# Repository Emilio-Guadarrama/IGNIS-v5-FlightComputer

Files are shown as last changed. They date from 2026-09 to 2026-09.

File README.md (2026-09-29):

# IGNIS v5 Flight Computer
### Ignitia Rocket Lab · Tecnológico de Monterrey GDL

---

## What is this?

IGNIS v5 is the fifth revision of Ignitia Rocket Lab's SRAD (Student Researched and Developed)
flight computer, a general-purpose avionics platform for high-power student rockets.

It handles the full flight from liftoff to recovery: sensor fusion, apogee detection,
pyrotechnic deployment, real-time LoRa telemetry, GNSS tracking and flight data logging.
Apogee is detected in flight rather than pre-programmed, so the same board can fly
missions from 500 m to 3 km without hardware changes.

---

## Competitions

IGNIS is used in the competitions Ignitia Rocket Lab takes part in or plans to join:

| Competition | Name | Location |
|---|---|---|
| **IREC** | Intercollegiate Rocket Engineering Competition, Spaceport America Cup | New Mexico, USA |
| **LASC** | Latin American Space Challenge | Brazil |
| **ENMICE** | Encuentro Mexicano de Ingeniería en Cohetería Experimental | Mexico |

---

## What's New in v5

v5 includes the lessons from the bench tests, flight tests and design reviews of the
previous versions. **All the areas of opportunity identified in earlier revisions have been solved**:

- **Reliability:** improved USB-C, power and pyro circuits.
- **Sensors:** updated IMU and barometer with a wider measurement range.
- **Manufacturability:** all assembled parts are available for **assembly at JLCPCB**, with alternates available in Mexico.
- **Documentation:** consistent schematic sheets and net names, and a BOM ready for assembly.

---

## Hardware at a Glance

| Block | Component |
|---|---|
| MCU | ESP32-S3-WROOM-1-N16R8 · 16 MB Flash / 8 MB PSRAM |
| RF Telemetry | RFM95W · 915 MHz LoRa · SMA antenna port |
| GNSS | u-blox SAM-M10Q · integrated patch antenna |
| IMU | LSM6DSV32X · 6-DOF · ±32 g / ±4000 dps |
| Barometer | Infineon DPS368 *(BMP280 drop-in compatible)* |
| Storage | MicroSD · SPI · card detect |
| Power | Dual AMS1117 · VBAT → 5 V → 3.3 V · battery voltage monitoring |
| USB | USB-C 2.0 · ESD protected · native USB programming |
| Debug | JST-SH 4-pin UART |
| Pyro | 2 channels, optically isolated MOSFET deployment with continuity sensing |
| Indicators | 3× WS2812B RGB · status LEDs · piezo buzzer |
| PCB | 4-layer · Altium Designer · JLCPCB fabrication and assembly |
| Apogee range | Adaptive, real-time apogee detection · 500 m to 3 km rockets |

---

## System Architecture

```mermaid
flowchart TD
    BAT[VBAT<br/>vehicle battery]

    BAT --> LDO5[AMS1117-5.0<br/>VBAT to 5 V]
    LDO5 --> RAIL5[5 V rail]
    USB[USB-C 2.0] --> ORING[Schottky power path]
    ORING --> RAIL5
    RAIL5 --> LDO33[AMS1117-3.3<br/>5 V to 3.3 V]
    LDO33 --> RAIL33[3.3 V rail]

    USB --> USBPROT[ESD protection]
    USBPROT --> MCU[ESP32-S3-WROOM-1-N16R8<br/>16 MB Flash / 8 MB PSRAM]
    BAT --> VMON[Battery voltage divider]
    VMON --> MCU

    RAIL33 --> IMU[LSM6DSV32X IMU<br/>±32 g / ±4000 dps]
    RAIL33 --> BARO[DPS368 barometer<br/>BMP280 footprint compatible]
    RAIL33 --> GNSS[u-blox SAM-M10Q GNSS]
    RAIL33 --> LORA[RFM95W LoRa<br/>915 MHz]
    RAIL33 --> SD[MicroSD<br/>SPI + card detect]

    IMU --> MCU
    BARO --> MCU
    GNSS --> MCU
    MCU <--> LORA
    MCU <--> SD
    LORA --> ANT[SMA antenna]

    MCU --> PYRO[2 × optically isolated<br/>pyro channels]
    BAT --> PYRO
    PYRO --> CONT[Continuity sensing]
    CONT --> MCU

    MCU --> IND[3 × WS2812B · status LEDs<br/>piezo buzzer]
    MCU <--> DEBUG[JST-SH 4-pin UART debug]
```

---

## Project Structure

```
IGNIS-v5-FlightComputer/
├── Schematics/
│   ├── Main.SchDoc
│   ├── Power.SchDoc
│   ├── RF_LoRa_&_GPS.SchDoc
│   ├── Sensors.SchDoc
│   ├── Storage.SchDoc
│   ├── Indicators.SchDoc
│   └── Pyros.SchDoc
├── PCB/
│   └── IGNIS_v5.PcbDoc
├── Libraries/
├── BOM/
└── Fabrication/
```

---

## Design & Development

**Lead Designer & Author:** [Emilio Guadarrama](https://github.com/Emilio-Guadarrama)  
Vice President, Ignitia Rocket Lab · Avionics & Electronics Lead

**Pyro Circuit:** Aristoteles Prieto  
**Team President:** Maximiliano Funoy Serrano  
**Faculty Advisor:** Dr. José Luis Henríquez Mercado

## Team

**Ignitia Rocket Lab**  
Tecnológico de Monterrey, Campus Guadalajara

📧 ignitia.rocketlab@gmail.com

---

## License

This project is open source under the [MIT License](LICENSE). You are free to use, modify and
share the design, including for your own rockets, as long as the original copyright notice is kept.

---

**Contact the author:** Emilio Guadarrama · [emilio.guadarrama@outlook.com](mailto:emilio.guadarrama@outlook.com)

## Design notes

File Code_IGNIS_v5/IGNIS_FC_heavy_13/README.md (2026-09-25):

# IGNIS v2 Flight Computer — firmware v13

Ignitia Rocket Lab · Tecnológico de Monterrey, Campus Guadalajara
LASC 2026 · Rocket Challenge, Mission ID 22

Post-FLIGHT051 / FLIGHT052 revision. FLIGHT052 is the flight where the FC
reset mid-descent and lost the entire post-apogee trace that the RRC3 backup
altimeter still has — this revision's centerpiece is a resume mechanism so
that doesn't happen again, plus the pyro-circuit correction the netlists
turned up. Every change is traced to a number in the flight logs or to the
schematic/netlists. Read `docs/CHANGELOG.md` first (v13 section is at the
top).

```
IGNIS_FC_heavy_13/
├── IGNIS_FC_heavy_13.ino    main sketch (boot counter, NO-GO tone + banner, RTC resume)
├── Config.h                 thresholds, interlocks, mode flags, pin map, RTC/I2C/flush tuning
├── FlightData.h             shared struct + lastPyroEventMs + RtcFlightState (v13 resume struct)
├── FlightState.h            FSM, baro velocity, tilt, failsafes, interlock, resume/sync (v13)
├── Pyro.h                   gate drive limiting, fire-event timestamp, RTC fired-flag persistence (v13)
├── DataLogger.h             post-pyro bounded flush, forensic CSV columns + `resumed` (v13), resume-reopen
├── Telemetry.h              98-byte v11/v12 packet — UNCHANGED this revision, see note below
├── Sensors.h                readBattery() extracted for the boot NO-GO, I2C timeout + runtime recovery (v13)
├── StatusIndicator.h        NOGO_MELODY, preflightNoGo(), persistent LED2
├── Dashboard.h              MODE / FSM / BOOT rows, NO-GO warnings (no longer cites a past flight — see CHANGELOG)
├── docs/
│   ├── CHANGELOG.md              <- read this first (v13, then v12, then v11)
│   ├── PREFLIGHT_VALIDATION.md   <- REC 8.4.2 test plan
│   ├── LIBRARIES.md              versions, UART jig, compile flags
│   └── install_libraries.sh
└── groundstation/
    ├── GroundStation_TelemetryPacket_v12.h   <- still named v12: packet layout is unchanged, see note below
    └── telemetry_parser_v12.py
```

**Groundstation files are still named `_v12` on purpose.** v13 only adds a
column to the SD CSV (`resumed`) — it does not touch `TelemetryPacket`, the
radio packet struct. Renaming files that carry no actual change would just
make history harder to follow; rename them the revision the packet itself
changes.

## Flight-configuration flags — CHECK THESE EVERY TIME

| Flag | Flight value | Effect if wrong |
|---|---|---|
| `GROUND_TEST_MODE` | **false** | If true: altitude interlock drops to 1.5 m — a bump can fire the drogue on the ground |
| `SINGLE_EVENT_MODE` | `true` unless BOTH channels read `cont:OK` | If false with an unwired channel: fires into an open loop, which is a reset risk |
| `APOGEE_TIMEOUT_MS` | Burnout→apogee time + margin | Too short: deployment at high speed, shredded parachute |
| `MIN_APOGEE_ALT_M` | 30 m | Too high: no deployment on an underperforming flight |
| `RTC_RESUME_ENABLED` (new, v13) | **true** | If false: an in-flight reset goes back to the FLIGHT051/052 behavior — reboots cold into `STATE_ARMED` and loses the rest of the flight |
| `I2C_TIMEOUT_MS` / `I2C_FAIL_RECOVERY_THRESHOLD` (new, v13) | 50 ms / 10 | Too low: spurious bus-recovery resets on a momentarily slow but otherwise fine bus |
| `PYRO_WINDOW_FLUSH_INTERVAL_MS` (new, v13) | 100 ms | Too low: back to near-every-row blocking SD flushes right after a fire, one of this revision's own watchdog-reset suspects |

The boot banner prints all of these (plus `last_op` and, on a resume boot, a
`RESUME:` banner line). Read it.

## Before you flash anything

1. **This has not been compiled.** Brace and parenthesis balance was verified
   programmatically on every file; that is not a clean build. Compile first
   and fix trivial errors rather than assuming a patch is wrong.
2. **Verify `Wire.setTimeOut()` against your installed ESP32 Arduino core
   version.** It's a real API on recent cores; confirm it before flashing
   rather than discovering a compile error on the pad.
3. **Bench-test the RTC resume path itself, in `GROUND_TEST_MODE`.** Force a
   reset mid-flight-simulation (e.g. power-cycle or trigger the watchdog
   deliberately) and confirm the FC comes back in the correct phase, with
   `resumed=1` in the next CSV rows and the same log file continuing rather
   than a new one. This is the core new mechanism in v13 and it has not been
   flight- or bench-verified yet.
4. **Determine why `pyro1_cont` reads 0.** Still open — this needs a
   physical continuity check on the CH1 e-match loop, it is not something
   firmware can diagnose or fix.
5. ~~Fit the 330 Ω gate resistors.~~ **Resolved — not actually missing.**
   The netlists (`Pyros.NET`/`Pyros2.NET`) confirm `R34` (100 Ω) is present
   in series with the fire-side opto LED, and ignition current is switched
   by an isolated MOSFET (`Q5`), not the opto. See `docs/CHANGELOG.md`
   v13 "Closed from v12."
6. **Re-tune `APOGEE_TIMEOUT_MS`** to the predicted profile. It is a
   deployment trigger, not a comment.
7. **Update the ground station in the same commit, if you change the radio
   packet.** Not needed for v13 itself (see the groundstation note above),
   but the packet is 98 bytes and the struct is packed — a mismatch decodes
   silently into garbage the moment it does change.

## The two sentences that matter

FLIGHT051→FLIGHT052: the flight computer reset mid-coast — confirmed
`reset_reason=5` (interrupt watchdog), battery steady at ~8.0 V throughout,
before any pyro command existed — then rebooted cold into `STATE_ARMED` and
detected the entire rest of the flight (apogee, descent, landing) as if it
were a new, stationary boot. The RRC3 backup altimeter has the full descent
trace; the FC's own SD log does not. v13's RTC resume mechanism exists
specifically so a reset like this keeps the flight computer *in* the flight
instead of restarting it.

FLIGHT018 (carried forward from v12, still true): the flight software
commanded a drogue fire at 0.80 m *below* the launch reference, off a hand
jerk on a 3-metre pulley. The v12 altitude interlock exists so that cannot
happen again, and v13 does not change it.

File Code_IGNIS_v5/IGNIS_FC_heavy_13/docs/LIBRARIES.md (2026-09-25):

# Libraries and toolchain — IGNIS FC v11

Third-party libraries are **not bundled** in this archive. They carry their own
licences, and vendoring frozen copies into the flight repo is how version
drift becomes untraceable — you already have one instance of that (the
installed RadioHead build has no `setSyncWord()`, which is why `Telemetry.h`
writes register `0x39` directly).

Install from Library Manager or with the script below, then record the exact
versions you flew in the mission report.

---

## Board package

| Item | Value |
|---|---|
| Core | `esp32:esp32` (Espressif Systems) |
| Version | **3.3.10** — this is what the codebase targets |
| Board | ESP32S3 Dev Module |
| Flash Size | 8 MB (64 Mb) — module is `ESP32-S3-WROOM-1-N8R8` |
| PSRAM | **OPI PSRAM** (8 MB Octal) |
| Partition Scheme | 8M with spiffs (3MB APP / 1.5MB SPIFFS) |
| USB CDC On Boot | Enabled (leave Disabled if programming over the UART jig) |
| Upload Speed | 921600 (drop to 115200 on the UART jig if unstable) |

The core version matters. `StatusIndicator.h` branches on
`ESP_ARDUINO_VERSION_MAJOR >= 3` for the LEDC API — the `< 3` branch is a
defensive fallback that has **not** been validated on this hardware.

## Libraries

| Library | Author | Version used | Notes |
|---|---|---|---|
| RadioHead | Mike McCauley | **1.122** (as installed) | `RH_RF95` only. `setSyncWord()` absent — do not "fix" `Telemetry.h` by calling it |
| TinyGPSPlus | Mikal Hart | 1.1.0 | NMEA parsing, `Sensors.h` |
| Adafruit NeoPixel | Adafruit | 1.12.3 | WS2812B status LEDs |

Built into the ESP32 core, nothing to install: `SPI`, `SD`, `Wire`,
`Preferences`, `esp_system`, `driver/gpio`.

BMP180 and MPU6050 use raw-register drivers in `Sensors.h`. Do **not** install
`Adafruit_BMP085` or `Adafruit_MPU6050` — they are not used and will only
confuse whoever picks this up next.

---

## Install

```bash
arduino-cli core update-index
arduino-cli core install esp32:esp32@3.3.10

arduino-cli lib install "RadioHead"
arduino-cli lib install "TinyGPSPlus@1.1.0"
arduino-cli lib install "Adafruit NeoPixel@1.12.3"
```

`install_libraries.sh` in this folder does the same and then prints the
resolved versions so you can paste them into the mission report.

## Compile

```bash
arduino-cli compile \
  --fqbn esp32:esp32:esp32s3:PSRAM=opi,FlashSize=8M,PartitionScheme=default_8MB,CDCOnBoot=cdc \
  --warnings all \
  IGNIS_FC_heavy_11
```

## Upload over the UART jig (bypasses the failing USB-C connectors)

Five of the flight computers have intermittent or dead USB-C. The connector is
only needed for programming — the boards log and fly correctly on battery
power alone. A CP2102 or CH340 adapter on the UART0 pins removes the
dependency entirely.

```
Adapter TX  ->  IO44  (ESP32 U0RXD)
Adapter RX  ->  IO43  (ESP32 U0TXD)
Adapter GND ->  board GND
Boot button ->  IO0 to GND
Reset       ->  EN to GND (momentary)
```

Entering download mode: hold IO0 low, pulse EN low then release, release IO0.

```bash
arduino-cli upload -p /dev/ttyUSB0 \
  --fqbn esp32:esp32:esp32s3:PSRAM=opi,FlashSize=8M,CDCOnBoot=default \
  IGNIS_FC_heavy_11
```

Set **USB CDC On Boot: Disabled** when programming this way, or `Serial` output
goes to the USB peripheral instead of UART0 and the console will look dead.

---

## Compile verification status

This firmware has **not** been compiled against the real toolchain — the build
environment used to produce these patches has no ESP32 core installed. Brace
and parenthesis balance was verified programmatically on every file; that is
not the same as a clean compile.

**Compile it before you flash anything, and fix trivial errors rather than
assuming a patch is wrong.**

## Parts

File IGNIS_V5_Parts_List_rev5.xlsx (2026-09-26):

IGNIS V5 component list
Mouser, DigiKey and SnapMagic links open a search for the exact part number. Stock checked Sep 25, 2026.
Status |  | Component name | ID # (part number) | Designator on schematic | # | LCSC | UNIT Electronics | Mouser MX | DigiKey MX | SnapMagic (symbol + footprint) | Notes
MICROCONTROLLER
Keep | TRUE | ESP32-S3 module 16 MB / 8 MB PSRAM | ESP32-S3-WROOM-1-N16R8 | MCU1 | 1 | C2913202 (https://www.lcsc.com/product-detail/C2913202.html) | UNIT (https://uelectronics.com/producto/esp32-s3-wroom-1-n16r8-16mb-flash/) | Mouser (https://www.mouser.mx/c/?q=ESP32-S3-WROOM-1-N16R8) | DigiKey (https://www.digikey.com.mx/es/products/result?keywords=ESP32-S3-WROOM-1-N16R8) | SnapMagic (https://www.snapeda.com/search/?q=ESP32-S3-WROOM-1-N16R8) | Fix USB D+/D− swap on Main sheet
POWER
Keep | TRUE | LDO 5 V | AMS1117-5.0 | U1 | 1 | C6187 (https://www.lcsc.com/product-detail/C6187.html) | UNIT (https://uelectronics.com/producto/ams1117-regulador-smd-5v-1a-sot-223/) | Mouser (https://www.mouser.mx/c/?q=AMS1117-5.0) | DigiKey (https://www.digikey.com.mx/es/products/result?keywords=AMS1117-5.0) | SnapMagic (https://www.snapeda.com/search/?q=AMS1117-5.0) | Kept for V5. Large copper + thermal vias; thermal test decides V6
Keep | TRUE | LDO 3.3 V | AMS1117-3.3 | U2 | 1 | C6186 (https://www.lcsc.com/product-detail/C6186.html) | UNIT (https://uelectronics.com/producto/ams1117-regulador-smd-3-3v-1a-sot-223/) | Mouser (https://www.mouser.mx/c/?q=AMS1117-3.3) | DigiKey (https://www.digikey.com.mx/es/products/result?keywords=AMS1117-3.3) | SnapMagic (https://www.snapeda.com/search/?q=AMS1117-3.3) | Kept (user decision)
Changed | TRUE | Schottky 40 V / 2 A SMA | SS24 | D1 | 1 | C50645 (https://www.lcsc.com/product-detail/C50645.html) | UNIT (https://uelectronics.com/producto/schottky-40v-2a-sma-ss24/) | Mouser (https://www.mouser.mx/c/?q=SS24) | DigiKey (https://www.digikey.com.mx/es/products/result?keywords=SS24) | SnapMagic (https://www.snapeda.com/search/?q=SS24) | SMA footprint (replaces SS24SHE3_B/H)
New | TRUE | USB ESD diode 5 V bidirectional (one per data line) | ESD9B5.0ST5G | D9, D10 (new) | 2 | C111566 (https://www.lcsc.com/product-detail/C111566.html) | UNIT (https://uelectronics.com/producto/diodo-esd-smdesd9b5-0st5g/) | Mouser (https://www.mouser.mx/c/?q=ESD9B5.0ST5G) | DigiKey (https://www.digikey.com.mx/es/products/result?keywords=ESD9B5.0ST5G) | SnapMagic (https://www.snapeda.com/search/?q=ESD9B5.0ST5G) | SOD-923, 15 pF — fine for USB full-speed. Alt: USBLC6-2SC6 (C7519)
CONNECTORS
Keep | TRUE | USB-C 16-pin (USB 2.0) | TYPE-C-31-M-12 | J1 | 1 | C165948 (https://www.lcsc.com/product-detail/C165948.html) | UNIT (https://uelectronics.com/producto/conector-usb-tipo-hembra-smd-type-c-31-m-12/) | Mouser (https://www.mouser.mx/c/?q=TYPE-C-31-M-12) | DigiKey (https://www.digikey.com.mx/es/products/result?keywords=TYPE-C-31-M-12) | SnapMagic (https://www.snapeda.com/search/?q=TYPE-C-31-M-12)
Keep | TRUE | SMA edge connector 50 Ω | BWSMA-KE-Z001 | J2 | 1 | C496549 (https://www.lcsc.com/product-detail/C496549.html) | UNIT (https://uelectronics.com/producto/conectores-sma-hembra-vertical-y-horizontal/) | Mouser (https://www.mouser.mx/c/?q=BWSMA-KE-Z001) | DigiKey (https://www.digikey.com.mx/es/products/result?keywords=BWSMA-KE-Z001) | SnapMagic (https://www.snapeda.com/search/?q=BWSMA-KE-Z001) | UNIT listing is generic SMA — confirm edge-mount
Changed | FALSE | MicroSD socket push-push | THD2528-11SD-GF | J3 | 1 | C283232 (https://www.lcsc.com/product-detail/C283232.html) | UNIT (https://uelectronics.com/producto/thd2528-11sd-gf-conector-para-memoria-micro-sd/) | Mouser (https://www.mouser.mx/c/?q=THD2528-11SD-GF) | DigiKey (https://www.digikey.com.mx/es/products/result?keywords=THD2528-11SD-GF) | SnapMagic (https://www.snapeda.com/search/?q=THD2528-11SD-GF) | Pin 9 CD → SD_DETECT (IO42) with R28 as 10 k pull-UP; shell pads MP1–4 to GND. Check CD polarity with a meter. Tape card for flight
Keep | TRUE | JST-SH 4-pin right-angle (debug UART) | SM04B-SRSS-TB(LF)(SN) | J4 | 1 | C160404 (https://www.lcsc.com/product-detail/C160404.html) | UNIT (https://uelectronics.com/producto/conector-jst-sr-4-pines-horizontal-sm04b-srss-tblfsn/) | Mouser (https://www.mouser.mx/c/?q=SM04B-SRSS-TB%28LF%29%28SN%29) | DigiKey (https://www.digikey.com.mx/es/products/result?keywords=SM04B-SRSS-TB%28LF%29%28SN%29) | SnapMagic (https://www.snapeda.com/search/?q=SM04B-SRSS-TB%28LF%29%28SN%29)
Changed | FALSE | Screw terminal 4-pin, fixed, 3.81 mm pitch (e-match leads) | DB125-3.81-4P-GN-S | P1 | 1 | C395880 (https://www.lcsc.com/product-detail/C395880.html) | — | Mouser (https://www.mouser.mx/c/?q=DB125-3.81-4P-GN-S) | DigiKey (https://www.digikey.com.mx/es/products/result?keywords=DB125-3.81-4P-GN-S) | SnapMagic (https://www.snapeda.com/search/?q=DB125-3.81-4P) | DORABO, fixed screw terminal (not pluggable, so nothing can loosen in flight). 3.81 mm pitch, 10 A, 300 V, 16–26 AWG, M2 screws. LCSC ~36,495 in stock (Sep 26, 2026). Replaces Dinkle EC381V-04P-BL (C7178935, out of stock). Use this part's own footprint (EasyEDA/SnapMagic): same pitch, but body and hole sizes can differ. Fallback: leave unassembled at JLCPCB and hand-solder in Mexico. Pinout: 1 VBAT, 2 EMATCH_CH1_N, 3 VBAT, 4 EMATCH_CH2_N. Not at UNIT.
New | TRUE | XT30 locking/waterproof male connector (battery pigtail, off-board) | XT30APW-M | J5 | 1 | C5818955 (https://www.lcsc.com/product-detail/C5818955.html) | UNIT (https://uelectronics.com/producto/conector-xt30-par-macho-hembra/) | Mouser (https://www.mouser.mx/c/?q=XT30APW-M) | DigiKey (https://www.digikey.com.mx/es/products/result?keywords=XT30APW-M) | SnapMagic (https://www.snapeda.com/search/?q=XT30APW-M) | Locking tab recommended for vibration resistance on the battery-side pigtail. Not at UNIT as the locking APW variant (standard XT30U pair only) — build pigtail by hand
RF & GPS
Changed | TRUE | LoRa transceiver 915 MHz | RFM95W-915S2 | U4 | 1 | C6760738 (https://www.lcsc.com/product-detail/C6760738.html) | UNIT (https://uelectronics.com/producto/rfm95w-915mhz-transceptor-lora/) | Mouser (https://www.mouser.mx/c/?q=RFM95W-915S2) | DigiKey (https://www.digikey.com.mx/es/products/result?keywords=RFM95W-915S2) | SnapMagic (https://www.snapeda.com/search/?q=RFM95W-915S2) | Same footprint; hand-solder
Keep | TRUE | GNSS module with patch antenna | SAM-M10Q-00B | U9 | 1 | C5443880 (https://www.lcsc.com/product-detail/C5443880.html) | — | Mouser (https://www.mouser.mx/c/?q=SAM-M10Q-00B) | DigiKey (https://www.digikey.com.mx/es/products/result?keywords=SAM-M10Q-00B) | SnapMagic (https://www.snapeda.com/search/?q=SAM-M10Q-00B) | LCSC 10 pcs @ $23; Mouser 5,005 @ $10.92. Rename RESET/EXTINT nets
SENSORS
Changed | FALSE | 6-axis IMU ±32 g / ±4000 dps | LSM6DSV32XTR | U10 | 1 | C22461202 (https://www.lcsc.com/product-detail/C22461202.html) | — | Mouser (https://www.mouser.mx/c/?q=LSM6DSV32XTR) | DigiKey (https://www.digikey.com.mx/es/products/result?keywords=LSM6DSV32XTR) | SnapMagic (https://www.snapeda.com/search/?q=LSM6DSV32XTR) | LCSC ~5,963 @ $4.39. LGA-14 2.5×3. Spares: buy on LCSC. Backup: LSM6DSO32TR (C1864162)
Changed | TRUE | Barometric pressure sensor | DPS368XTSA1 | U11 | 1 | C3232508 (https://www.lcsc.com/product-detail/C3232508.html) | UNIT (https://uelectronics.com/producto/bmp280-ic-smd-sensor-presion/) | Mouser (https://www.mouser.mx/c/?q=DPS368XTSA1) | DigiKey (https://www.digikey.com.mx/es/products/result?keywords=DPS368XTSA1) | SnapMagic (https://www.snapeda.com/search/?q=DPS368XTSA1) | JLCPCB places it. Pin/footprint-identical to BMP280 (UNIT AR2339 as hand-fit alternate). SDO low → 0x76. Firmware reads chip ID
INDICATORS
Keep | TRUE | Addressable RGB LED 5050 | WS2812B-B/T | LED1, LED2, LED3 | 3 | C2761795 (https://www.lcsc.com/product-detail/C2761795.html) | UNIT (https://uelectronics.com/producto/neopixel-rgb-5x5mm-smd-ws2812b-b/) | Mouser (https://www.mouser.mx/c/?q=WS2812B-B%2FT) | DigiKey (https://www.digikey.com.mx/es/products/result?keywords=WS2812B-B%2FT) | SnapMagic (https://www.snapeda.com/search/?q=WS2812B-B%2FT) | Rename footprint LED3535→LED5050
Keep | TRUE | Magnetic buzzer 2.7 kHz (passive) | MLT-8530 | LS1 | 1 | C94599 (https://www.lcsc.com/product-detail/C94599.html) | UNIT (https://uelectronics.com/producto/unit-devlab-80db-passive-buzzer-module/) | Mouser (https://www.mouser.mx/c/?q=MLT-8530) | DigiKey (https://www.digikey.com.mx/es/products/result?keywords=MLT-8530) | SnapMagic (https://www.snapeda.com/search/?q=MLT-8530) | Rated 3.6 V: move to VCC_3V3. Not at UNIT
Changed | TRUE | Red LED 0805 | NCD0805R1 | D2, D3, D4, D6, D7, D8 | 6 | C84256 (https://www.lcsc.com/product-detail/C84256.html) | UNIT (https://uelectronics.com/producto/led-rojo-smd-0805-ncd0805r1/) | Mouser (https://www.mouser.mx/c/?q=NCD0805R1) | DigiKey (https://www.digikey.com.mx/es/products/result?keywords=NCD0805R1) | SnapMagic (https://www.snapeda.com/search/?q=NCD0805R1)
Changed | TRUE | Switching diode (buzzer flyback) | 1N4148W | D5 | 1 | C81598 (https://www.lcsc.com/product-detail/C81598.html) | UNIT (https://uelectronics.com/producto/1n4148w-diodo-75v-150ma-smd/) | Mouser (https://www.mouser.mx/c/?q=1N4148W) | DigiKey (https://www.digikey.com.mx/es/products/result?keywords=1N4148W) | SnapMagic (https://www.snapeda.com/search/?q=1N4148W)
TRANSISTORS & PYRO
Keep | TRUE | NPN 25 V / 500 mA | S8050 | Q1, Q4 | 2 | C2146 (https://www.lcsc.com/product-detail/C2146.html) | UNIT (https://uelectronics.com/producto/transistor-npn-500ma-25v-s8050/) | Mouser (https://www.mouser.mx/c/?q=S8050) | DigiKey (https://www.digikey.com.mx/es/products/result?keywords=S8050) | SnapMagic (https://www.snapeda.com/search/?q=S8050)
Keep | TRUE | PNP 25 V / 1.5 A | SS8550 | Q3, Q6 | 2 | C8542 (https://www.lcsc.com/product-detail/C8542.html) | UNIT (https://uelectronics.com/producto/transistor-pnp-1-5a-25v-ss8550/) | Mouser (https://www.mouser.mx/c/?q=SS8550) | DigiKey (https://www.digikey.com.mx/es/products/result?keywords=SS8550) | SnapMagic (https://www.snapeda.com/search/?q=SS8550)
Keep | TRUE | N-MOSFET 60 V / 5 A (SOT-223) | NCE6005AR | Q2, Q5 | 2 | C189606 (https://www.lcsc.com/product-detail/C189606.html) | UNIT (https://uelectronics.com/producto/mosfet-n-60v-5a-smd-nce6005ar/) | Mouser (https://www.mouser.mx/c/?q=NCE6005AR) | DigiKey (https://www.digikey.com.mx/es/products/result?keywords=NCE6005AR) | SnapMagic (https://www.snapeda.com/search/?q=NCE6005AR)
Keep | TRUE | N-MOSFET 30 V / 270 mA (SC-70) | NTS4001NT1G | Q7 | 1 | C116738 (https://www.lcsc.com/product-detail/C116738.html) | UNIT (https://uelectronics.com/producto/unit-devlab-80db-passive-buzzer-module/) | Mouser (https://www.mouser.mx/c/?q=NTS4001NT1G) | DigiKey (https://www.digikey.com.mx/es/products/result?keywords=NTS4001NT1G) | SnapMagic (https://www.snapeda.com/search/?q=NTS4001NT1G) | Not at UNIT, but it is from the SMD Buzzer module
Changed | TRUE | Optocoupler SMD-4, CTR GB 100–600 % | TLP521GB-S (UMW) | U5, U6, U7, U8 | 4 | C364143 (https://www.lcsc.com/product-detail/C364143.html) | UNIT (https://uelectronics.com/producto/optoacoplador-a-transistor-smd-tlp521gb-s/) | Mouser (https://www.mouser.mx/c/?q=TLP521GB-S+%28UMW%29) | DigiKey (https://www.digikey.com.mx/es/products/result?keywords=TLP521GB-S+%28UMW%29) | SnapMagic (https://www.snapeda.com/search/?q=TLP521GB-S+%28UMW%29) | JLCPCB supplies from LCSC
Keep | TRUE | Button / Tactile switch | SKRPABE010 | S1, S2 | 2 | C115360 (https://www.lcsc.com/product-detail/C115360.html) | UNIT (https://uelectronics.com/producto/skrpabe010-micro-switch-4-6x3-2x2-5-mm-smd/) | Mouser (https://www.mouser.mx/c/?q=SKRPABE010) | DigiKey (https://www.digikey.com.mx/es/products/result?keywords=SKRPABE010) | SnapMagic (https://www.snapeda.com/search/?q=SKRPABE010)
RESISTORS 0603 1 %
Changed | FALSE | Resistor 5.1 kΩ | 0603WAF5101T5E | R1, R2 | 2 | C23186 (https://www.lcsc.com/product-detail/C23186.html) | UNIT (https://uelectronics.com/producto/resistencias-smd-0603/) | Mouser (https://www.mouser.mx/c/?q=0603WAF5101T5E) | DigiKey (https://www.digikey.com.mx/es/products/result?keywords=0603WAF5101T5E) | Generic — use your 0603/0805 library
Changed | FALSE | Resistor 22 Ω | 0603WAF220JT5E | R3, R4 | 2 | C23345 (https://www.lcsc.com/product-detail/C23345.html) | UNIT (https://uelectronics.com/producto/resistencias-smd-0603/) | Mouser (https://www.mouser.mx/c/?q=0603WAF220JT5E) | DigiKey (https://www.digikey.com.mx/es/products/result?keywords=0603WAF220JT5E) | Generic — use your 0603/0805 library
Changed | FALSE | Resistor 33 Ω | 0603WAF330JT5E | R29 | 1 | C23140 (https://www.lcsc.com/product-detail/C23140.html) | UNIT (https://uelectronics.com/producto/resistencias-smd-0603/) | Mouser (https://www.mouser.mx/c/?q=0603WAF330JT5E) | DigiKey (https://www.digikey.com.mx/es/products/result?keywords=0603WAF330JT5E) | Generic — use your 0603/0805 library
Changed | FALSE | Resistor 100 Ω | 0603WAF1000T5E | R12, R17, R38, R40 | 4 | C22775 (https://www.lcsc.com/product-detail/C22775.html) | UNIT (https://uelectronics.com/producto/resistencias-smd-0603/) | Mouser (https://www.mouser.mx/c/?q=0603WAF1000T5E) | DigiKey (https://www.digikey.com.mx/es/products/result?keywords=0603WAF1000T5E) | Generic — use your 0603/0805 library
Changed | FALSE | Resistor 470 Ω | 0603WAF4700T5E | R33, R34 | 2 | C23179 (https://www.lcsc.com/product-detail/C23179.html) | UNIT (https://uelectronics.com/producto/resistencias-smd-0603/) | Mouser (https://www.mouser.mx/c/?q=0603WAF4700T5E) | DigiKey (https://www.digikey.com.mx/es/products/result?keywords=0603WAF4700T5E) | Generic — use your 0603/0805 library
Changed | FALSE | Resistor 680 Ω | 0603WAF6800T5E | R15, R20 | 2 | C23228 (https://www.lcsc.com/product-detail/C23228.html) | UNIT (https://uelectronics.com/producto/resistencias-smd-0603/) | Mouser (https://www.mouser.mx/c/?q=0603WAF6800T5E) | DigiKey (https://www.digikey.com.mx/es/products/result?keywords=0603WAF6800T5E) | Generic — use your 0603/0805 library
Changed | FALSE | Resistor 1 kΩ | 0603WAF1001T5E | R11, R13, R14, R16, R18, R19, R31, R32, R37, R39 | 10 | C21190 (https://www.lcsc.com/product-detail/C21190.html) | UNIT (https://uelectronics.com/producto/resistencias-smd-0603/) | Mouser (https://www.mouser.mx/c/?q=0603WAF1001T5E) | DigiKey (https://www.digikey.com.mx/es/products/result?keywords=0603WAF1001T5E) | Generic — use your 0603/0805 library
Changed | FALSE | Resistor 4.7 kΩ | 0603WAF4701T5E | R10, R21, R22 | 3 | C23162 (https://www.lcsc.com/product-detail/C23162.html) | UNIT (https://uelectronics.com/producto/resistencias-smd-0603/) | Mouser (https://www.mouser.mx/c/?q=0603WAF4701T5E) | DigiKey (https://www.digikey.com.mx/es/products/result?keywords=0603WAF4701T5E) | Generic — use your 0603/0805 library
Changed | FALSE | Resistor 10 kΩ | 0603WAF1002T5E | R7, R8, R23, R24, R25, R26, R27, R28, R30, R35, R36 | 11 | C25804 (https://www.lcsc.com/product-detail/C25804.html) | UNIT (https://uelectronics.com/producto/resistencias-smd-0603/) | Mouser (https://www.mouser.mx/c/?q=0603WAF1002T5E) | DigiKey (https://www.digikey.com.mx/es/products/result?keywords=0603WAF1002T5E) | Generic — use your 0603/0805 library
Changed | FALSE | Resistor 47 kΩ | 0603WAF4702T5E | R5 | 1 | C25819 (https://www.lcsc.com/product-detail/C25819.html) | UNIT (https://uelectronics.com/producto/resistencias-smd-0603/) | Mouser (https://www.mouser.mx/c/?q=0603WAF4702T5E) | DigiKey (https://www.digikey.com.mx/es/products/result?keywords=0603WAF4702T5E) | Generic — use your 0603/0805 library
Changed | FALSE | Resistor 100 kΩ | 0603WAF1003T5E | R6 | 1 | C25803 (https://www.lcsc.com/product-detail/C25803.html) | UNIT (https://uelectronics.com/producto/resistencias-smd-0603/) | Mouser (https://www.mouser.mx/c/?q=0603WAF1003T5E) | DigiKey (https://www.digikey.com.mx/es/products/result?keywords=0603WAF1003T5E) | Generic — use your 0603/0805 library
CAPACITORS 0805
Changed | FALSE | Capacitor 100 nF 50 V X7R | CC0805KRX7R9BB104 | C2, C4, C6, C8, C9, C11, C13, C14, C20, C21, C22, C23, C28, C29, C30, C31, C32, C33, C34 | 19 | C49678 (https://www.lcsc.com/product-detail/C49678.html) | UNIT (https://uelectronics.com/producto/cc0805krx7r9bb104-capacitor-ceramico-0805-100nf-50v/) | Mouser (https://www.mouser.mx/c/?q=CC0805KRX7R9BB104) | DigiKey (https://www.digikey.com.mx/es/products/result?keywords=CC0805KRX7R9BB104) | Generic — use your 0603/0805 library
Changed | FALSE | Capacitor 10 µF 25 V X5R | CL21A106KAYNNNE | C1, C5, C7, C15, C24, C25, C26 | 7 | C15850 (https://www.lcsc.com/product-detail/C15850.html) | UNIT (https://uelectronics.com/producto/tmk212bbj106kg-t-capacitor-ceramico-0805-10uf-25v/) | Mouser (https://www.mouser.mx/c/?q=CL21A106KAYNNNE) | DigiKey (https://www.digikey.com.mx/es/products/result?keywords=CL21A106KAYNNNE) | Generic — use your 0603/0805 library | UNIT part is TMK212BBJ106KG-T (same spec)
Changed | FALSE | Capacitor 22 µF 25 V X5R | CL21A226MAQNNNE | C3, C12, C19 | 3 | C45783 (https://www.lcsc.com/product-detail/C45783.html) | UNIT (https://uelectronics.com/producto/cl21a226maqnnne-capacitor-ceramico-0805-22uf-25v/) | Mouser (https://www.mouser.mx/c/?q=CL21A226MAQNNNE) | DigiKey (https://www.digikey.com.mx/es/products/result?keywords=CL21A226MAQNNNE) | Generic — use your 0603/0805 library | C3 raised from 10 µF
Changed | FALSE | Capacitor 1 µF 50 V X7R | CL21B105KBFNNNE | C10 | 1 | C28323 (https://www.lcsc.com/product-detail/C28323.html) | UNIT (https://uelectronics.com/producto/capacitor-ceramico-0805-1uf-50v-tcc0805x7r105k500dts/) | Mouser (https://www.mouser.mx/c/?q=CL21B105KBFNNNE) | DigiKey (https://www.digikey.com.mx/es/products/result?keywords=CL21B105KBFNNNE) | Generic — use your 0603/0805 library | UNIT part is TCC0805X7R105K500DTS (same spec)
 |  | Parts on V5 board (excl. red and yellow rows) |  |  | 20
 |  | Parts found at UNIT Electronics (lines) |  |  | 37 of 40

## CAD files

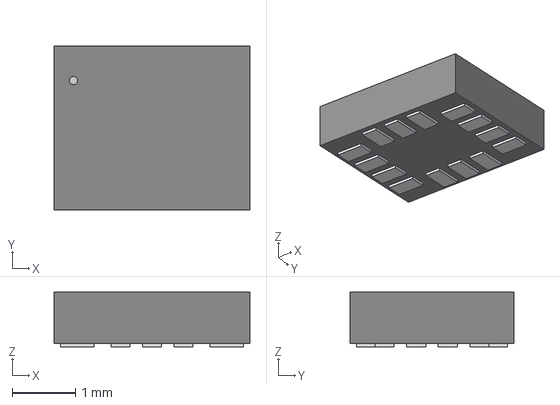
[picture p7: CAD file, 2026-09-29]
PCB_Project_IGNIS-v5/Components/6-axis IMU - LSM6DSV32XTR/LSM6DSV32XTR/LGA-14L_2p5X3p0X0p86_STM.step
3.10 x 2.59 x 0.866 mm

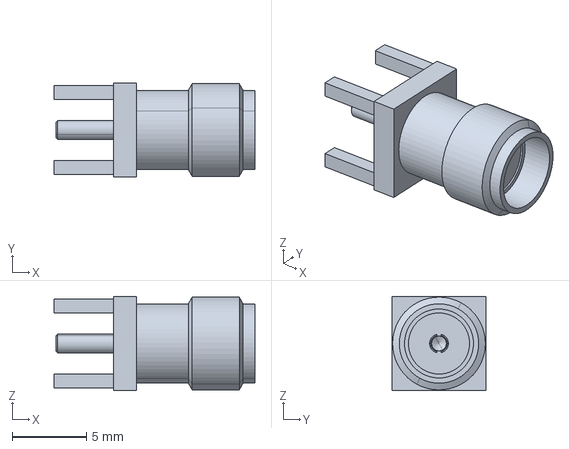
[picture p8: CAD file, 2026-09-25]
PCB_Project_IGNIS-v5/Components/SMA port - BWSMA-KE-Z001/82_SMA-50-0-41_133_NE.STEP
13.6 x 6.35 x 6.35 mm

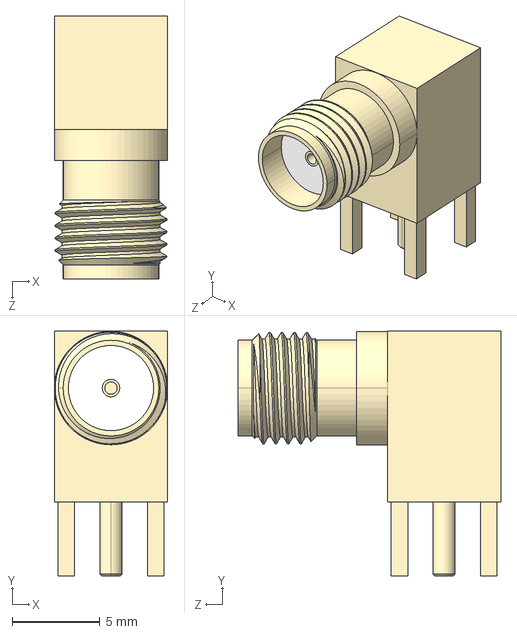
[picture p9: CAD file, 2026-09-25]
PCB_Project_IGNIS-v5/Components/SMA port - BWSMA-KE-Z001/SMA3D.STEP
6.46 x 13.9 x 15.0 mm

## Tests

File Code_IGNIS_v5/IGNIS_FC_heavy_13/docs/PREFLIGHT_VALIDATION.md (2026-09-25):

# v11 bench validation and pre-flight checklist

Ignitia Rocket Lab — LASC 2026, Mission ID 22
Departure for Iacanga: **26 August 2026**

Tests **3, 5 and 6** are the ones that satisfy REC 8.4.2 (successful ground
test of all recovery mechanisms, **mandatory annex to the Mission Report,
complete with dates and signatures**) and REC 8.4.3 (recovery electronics
demonstrate the ability to fire an electronic match). Record them properly —
photos, serial captures, signatures. Do not leave this for Brazil.

---

## Phase 0 — before any code runs

| # | Task | Pass criterion | Done |
|---|---|---|---|
| 0.1 | Multimeter across CH1 and CH2 terminals with e-match connected | Establishes **which channel the e-match is physically on**. FLIGHT072 fired CH1 with `pyro1_cont = 0`; CH2 read continuity and was never fired | ☐ |
| 0.2 | Confirm `Pyro.h` continuity polarity against the physical board | `cont = 1` with a known-good load, `cont = 0` with the loop open. If it does not track, the sense circuit is broken and every continuity reading is meaningless | ☐ |
| 0.3 | 330 Ω series resistor bodged onto `PYRO_CH1_GATE` and `PYRO_CH2_GATE` | Gate current < 15 mA measured | ☐ |
| 0.4 | MPU6050 `AD0` jumpered to GND on every board | Suspected cause of the FLIGHT073 IMU loss (`imu_valid = 0`, 12,970 rows) | ☐ |
| 0.5 | UART programming jig built (CP2102/CH340 on IO43/IO44) | Every board flashable without USB-C | ☐ |
| 0.6 | **Move the e-match to CH1** | `pyro1_cont` reads 1 at boot. It has read 0 across 23,196 rows | ☐ |
| 0.7 | Confirm `GROUND_TEST_MODE = false` and `SINGLE_EVENT_MODE = true` in the flashed build | Boot banner shows `ground_test:off  single_event:ON` | ☐ |

**Do not proceed past 0.1 and 0.2.** Everything downstream assumes you know
which channel is wired and that continuity readings mean something.

---

## Phase 1 — firmware bring-up

| # | Test | Pass criterion | Done |
|---|---|---|---|
| 1.1 | Compile v11 with the toolchain in `LIBRARIES.md` | Clean build, no warnings that touch the pyro or FSM paths | ☐ |
| 1.2 | Flash, open serial at 115200 | `boot_count` prints and increments by exactly 1 per power cycle | ☐ |
| 1.3 | Disconnect one e-match, reboot | NO-GO banner prints **and** `playNoGoTone()` sounds 3× with red LEDs | ☐ |
| 1.4 | Reconnect, reboot | Normal `ARMED_MELODY`, no NO-GO | ☐ |

---

## Phase 2 — pyro (live e-match, flight battery)

> Treat every powered board as live pyro. Eye protection. Clear the bench.

| # | Test | Pass criterion | Done |
|---|---|---|---|
| 2.1 | Fire a real e-match ×5, flight 2S3P LiPo, SD logging active | **5/5 ignition, 0 reboots.** `boot_count` unchanged across all five | ☐ |
| 2.2 | Inspect the SD log around each fire | Rows present continuously through and after the fire event — no 1.2 s hole | ☐ |
| 2.3 | Log VBAT during fire (scope on VBAT if available) | No excursion below 6.5 V (AMS1117-5.0 dropout) | ☐ |

If 2.1 shows any reboot, **stop**. Set `PYRO_GATE_REDUCED_DRIVE` to `false`,
confirm the 330 Ω bodge is present, and repeat. If it still reboots with a
resistor fitted and the loop open, the problem is not the gate drive and
needs a scope on the 3V3 rail before anything else happens.

If 2.1 shows a **misfire** (opto failed to switch), that is the reduced drive
strength. Set `PYRO_GATE_REDUCED_DRIVE` to `false` and repeat.

---

## Phase 3 — recovery system, vacuum chamber → REC 8.4.2 / 8.4.3 annex

Sealed jar plus a manual vacuum pump. Simulating 1000 m AGL from a ~1400 m
site needs roughly a 117 hPa reduction from ambient.

| # | Test | Pass criterion | Done |
|---|---|---|---|
| 3.1 | Full profile: ground → simulated apogee → descent, e-match connected | `deploy_trigger = 1`, drogue fires < 300 ms after peak | ☐ |
| 3.2 | Main deployment on the descent leg | Fires at ≤ 450 m AGL **and** ≥ 1500 ms after drogue (stagger holds) | ☐ |
| 3.3 | Repeat 3.1 with the BMP180 disconnected mid-coast | `deploy_trigger = 2` at `APOGEE_TIMEOUT_MS` after burnout | ☐ |
| 3.4 | Repeat with MPU6050 disconnected, shake vertically | BOOST entered via `BARO-BACKUP` (check the serial print) | ☐ |
| 3.5 | Tap/shock test with AD0 grounded | `imu_valid` stays 1 throughout | ☐ |

**Capture for the annex:** date, time, operators, board serial, firmware
version (`v11`), the SD log file, and signatures. Photos of the setup.

---

## Phase 3b — the open question: reset at low battery (v12)

The FLIGHT072 mid-air reset is **not** explained. The pulley tests that did
not reset ran at 8.10–8.12 V; FLIGHT072 flew at 7.73 V. That is an
uncontrolled variable, not a negative result.

| # | Test | Pass criterion | Done |
|---|---|---|---|
| 3b.1 | Discharge a pack to **7.73 V** — match it, do not approximate | Measured at rest, not under load | ☐ |
| 3b.2 | Repeat the pulley sequence ×5, `GROUND_TEST_MODE = true`, real e-match | `boot_count` does not increment in 5/5 | ☐ |
| 3b.3 | If it does increment, read `reset_reason` | 9 = brownout · 4/15 = GPIO overload · 4/5/6/7 = firmware crash | ☐ |
| 3b.4 | Scope on VBAT and 3V3, triggered on the gate pin | Settles it in one shot instead of five | ☐ |
| 3b.5 | 30-minute idle soak, board untouched | `boot_count` does not self-increment | ☐ |

## Phase 4 — system

| # | Test | Pass criterion | Done |
|---|---|---|---|
| 4.1 | 4-hour standby on the bench, VBAT logged | ECS 9.1.3. **Expected to fail as-is** — FLIGHT073 dropped 7.75 → 7.54 V in 464 s (~1.6 V/h). Measure it properly, then decide on light-sleep work | ☐ |
| 4.2 | Ground station updated to the v11 packet, end-to-end | 98-byte packets decode; `tilt_deg` / `boot_count` / `deploy_trigger` display correctly | ☐ |
| 4.3 | RF range test in flight configuration, antenna as mounted | Pad RSSI better than −115 dBm. FLIGHT072 sat at −123.6 dBm with 40.2 % loss — about 2 dB from total link failure | ☐ |
| 4.4 | RRC3 configured, independent battery, independent RBF | Drogue channel repurposed as backup main; main terminals unwired | ☐ |
| 4.5 | `APOGEE_TIMEOUT_MS` re-tuned to the actual predicted profile | Matches OpenRocket burnout→apogee plus margin | ☐ |
| 4.6 | `MIN_APOGEE_ALT_M` sanity-checked against the predicted apogee | 30 m must be well below the expected peak | ☐ |

---

## Pad procedure — every launch, no exceptions

1. Power the board. **Listen.** `ARMED_MELODY` = go. `NOGO_MELODY` = stop and
   find out why.
2. Confirm on the ground station: continuity green on the wired channel,
   `boot_count` noted, and **`battery_v` ≥ 7.80 V** — FLIGHT072 flew at
   7.73 V and that should have been a pad no-go.
3. Write the `boot_count` on the launch card. If it differs after recovery,
   the FC rebooted in flight.
4. Arm the RRC3 on its own pull-pin, independently.

FLIGHT072 was lost because step 1 existed only as a line of serial text that
nobody was reading. That is the whole reason the NO-GO tone was added.

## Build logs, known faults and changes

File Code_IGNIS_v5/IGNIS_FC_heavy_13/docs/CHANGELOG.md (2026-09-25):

# IGNIS v2 Flight Computer — firmware v13

**Date:** 2026-09-22
**Baseline:** `IGNIS_FC_heavy_12`
**Trigger:** FLIGHT051 / FLIGHT052 — the FC reset mid-flight and lost the
entire descent trace that the RRC3 backup altimeter still has; a follow-up
pyro-circuit review with E. Guadarrama (schematic image + `Pyros.NET` /
`Pyros2.NET` netlists + `Pyros.pdf`) plus direct analysis of the
`reset_reason` column in both CSVs.

---

## What FLIGHT051/FLIGHT052 proved

Both logs were pulled apart directly (`reset_reason`, `boot_count`,
`battery_v`, `state`, `pyro1_fired`, `timestamp_ms`).

1. **The reset is confirmed `reset_reason = 5` (`ESP_RST_INT_WDT`, the
   interrupt watchdog), not brownout.** `battery_v` sits at a steady
   8.00–8.06 V across the entire window — there is no voltage sag to
   correlate with the reset. The brownout hypothesis is closed for this
   specific event.
2. **It happened mid-`STATE_COAST`, before any pyro fire command existed
   in either log.** That rules out the gate-drive-overcurrent theory *for
   this reset* — nothing had fired yet — and it means the FC rebooted,
   re-ran full cold-start init (including MPU calibration and SD
   remount), and came back up in `STATE_ARMED` with zero memory of ever
   having flown. Apogee and the entire descent were then detected and
   logged as if this were a brand-new, stationary boot — which is why the
   RRC3 backup has a full descent trace and the FC does not.
3. **The pyro circuit itself is not the flaw it was thought to be.** The
   netlists confirm `R34` (100 Ω) *is* present in series with the
   fire-side opto LED, and ignition current does not flow through the
   opto at all — it's switched by an isolated N-MOSFET (`Q5`,
   NCE6005AR, 60 V / 5 A) driven through a push-pull BJT level-shifter
   (`Q4`/`Q6`). The "no series resistor on the gate opto leg" theory in
   `Pyro.h`'s v11/v12 comments was based on a misreading of the code
   comments against the schematic, not the actual board. **Walking that
   theory back** — see "Closed from v12" below.

What v13 does NOT resolve: what caused the *second* reset, ~434 ms after
`STATE_ARMED` re-fires the pyro command near the end of FLIGHT052.
`battery_v` at that point has not been isolated from the ignition current
step, so a VBAT-rail-sag-from-ignition cause is still the leading
hypothesis for that one — untested on the bench as of this revision. See
`FLIGHT051-052.md` analysis notes.

---

## Changes

### 1. RTC-persisted flight-state resume across an in-flight reset — `FlightData.h`, `Config.h`, `FlightState.h`, `.ino`

The actual fix for the FLIGHT051/052 finding above. `RTC_DATA_ATTR`
slow-memory (survives SW/panic/watchdog resets, not necessarily a full
brownout power-cycle) now holds a `RtcFlightState` breadcrumb: flight
phase, both pyro `_fired` flags, `maxAglSinceBoost`, ground-pressure
calibration, MPU bias, and the active log filename, tagged with a magic
number so a genuinely fresh cold boot is never mistaken for a resume.

`setup()` now checks `reset_reason != POWERON && rtcState.magic valid &&
phase >= BOOST` and, if true, skips straight to `resumeFlightState()`
instead of the cold-start `STATE_ARMED` path — the FC comes back up
already in the flight phase it was in, not stationary-armed, so descent
detection and pyro logic keep running instead of re-arming from scratch.

Deliberately **not** attempting to reconstruct absolute elapsed
flight time across the reset — `millis()` resets to 0 on every boot, and
back-computing a fake absolute timestamp is a worse failure mode than
simply re-arming each phase's own timers fresh on resume. This is a
conservative simplification, not an oversight: every timer that matters
(coast/drogue/main timeouts) re-starts cleanly from the resume moment.

### 2. Pyro fired-flag persistence — `Pyro.h`, `FlightData.h`, `.ino`

`d.pyro1_fired` / `d.pyro2_fired` are now part of the RTC breadcrumb and
are restored in `setup()` before the FSM resumes. Before v13 this latch
lived only in RAM — an in-flight reset after a real fire could let the
FSM call `fireChannel()` again on the next boot. That is not just a
logging gap: a channel that already fired has a burned-open bridgewire,
so re-asserting the gate drives `Q5` into a guaranteed-open loop — the
same electrical signature already implicated as a reset candidate
elsewhere in this project's history. Closed.

### 3. I2C bus hardening — `Sensors.h`

`Wire.setTimeOut(I2C_TIMEOUT_MS)` (50 ms) added so a stuck I2C bus can no
longer hang the sensor read indefinitely — a plausible contributor to an
interrupt-watchdog trip. Runtime bus recovery (previously only ever
invoked once, at boot) is now re-invoked from the flight loop itself
after `I2C_FAIL_RECOVERY_THRESHOLD` (10) consecutive failed reads, so a
bus that wedges mid-flight has a chance to recover without waiting for
the next reboot.

### 4. SD: reopen the existing log file on resume — `DataLogger.h`

`attemptSDMount()` takes an `isResume` flag. On a genuine resume with a
valid RTC-remembered filename, it reopens that **same** `/FLIGHTxxx.CSV`
(Arduino `SD`'s `FILE_WRITE` opens at EOF — append, not truncate) instead
of allocating a new one. This is what turns a pre-reset + post-reset
flight back into one continuous file instead of the FLIGHT051 /
FLIGHT052 split this revision exists to fix.

### 5. Bounded post-pyro flush interval — `Config.h`, `DataLogger.h`

The v11 "flush every row for `PYRO_FORCE_FLUSH_MS` after any fire event"
behavior is itself a watchdog-reset candidate — up to ~50 blocking SD
writes/second during the highest-vibration part of the flight. v13 keeps
the same forensic intent (bound worst-case data loss right after a fire
to well under a second) but flushes on a bounded
`PYRO_WINDOW_FLUSH_INTERVAL_MS` (100 ms) interval instead of every row,
far fewer blocking SD ops for effectively the same guarantee.

### 6. RTC "last operation" breadcrumb — `FlightData.h`, threaded through `Sensors.h` / `DataLogger.h` / `Pyro.h` / `Telemetry.h`

`rtcSetLastOp()` brackets I2C reads, SD mount, SD write, pyro fire, and
radio send with an `OP_*` marker persisted in the same RTC struct. If a
future reset happens mid-operation, the very next boot's banner prints
what the FC was doing when it went down (`last_op=...`) — this is the
single biggest lever for diagnosing *which* operation trips the
interrupt watchdog next time, since FLIGHT051/052 alone couldn't localize
it beyond "sometime in `STATE_COAST`."

### 7. New `resumed` CSV column — `DataLogger.h`

`resumed_this_boot` (1 if this boot restored flight state from RTC, 0 on
a genuine cold start) is appended to every log row. Lets post-flight
analysis immediately see where a resume happened in the row stream,
instead of inferring it from a `boot_count` jump.

### 8. Dashboard live output no longer names a past flight — `Dashboard.h`

The two `Serial.println` lines citing FLIGHT072 specifics
("`*** FLIGHT072 flew with CH1 OPEN`", "`*** FLIGHT072 flew at 7.73 V`")
are removed from `printDashboard()`'s live NO-GO block — a recurring
serial print is the wrong place for a one-off historical citation once
the underlying threshold check (open continuity / low VBAT) is doing the
actual work. The same FLIGHT072 references are **kept** in the one-time
`setup()` boot banner, unchanged — that context is worth remembering, just
not re-printing every dashboard cycle in flight.

---

## Closed from v12

**"Missing series resistor on the pyro gate opto leg" — was wrong for
this board.** The `Pyros.NET` / `Pyros2.NET` netlists (plus the
schematic image and `Pyros.pdf`) confirm `R34` = 100 Ω is present in
series with the fire-side opto LED, and that ignition current is
switched by an isolated N-MOSFET (`Q5`, NCE6005AR), not the opto itself.
`PYRO_GATE_REDUCED_DRIVE` and the "fit a 330 Ω resistor" note in `Pyro.h`
and prior changelogs described a hardware flaw that does not exist on the
as-built board. Left the code comments in place with a correction rather
than deleting the history — see `Pyro.h`'s header.

## Confirmed unrelated to this revision (no change needed)

- **Booting straight to `STATE_ARMED` from power-on is correct as-is.**
  The vehicle powers up already armed via the Remove-Before-Flight pin, by
  design and by rule (no additional action should be required to start
  the flight once the pin is pulled). This is unrelated to the resume
  fix above and was not changed.
- **Telemetry/logging were never state-gated to begin with.** `loop()`
  calls `logFlightData()` / `sendTelemetry()` unconditionally regardless
  of `d.state`, so GPS and full sensor data already keep transmitting
  through descent and landing on a boot that never reset. The actual gap
  FLIGHT051/052 exposed was the FSM not *reaching* the descent states
  after a reset in the first place — which is what item 1 above fixes.

---

## Still open after v13

| Item | Owner |
|---|---|
| ~~330 Ω series resistor on both pyro gate legs~~ — netlist-confirmed not needed; R34 (100 Ω) already present, MOSFET-switched | closed, see above |
| Determine why `pyro1_cont` reads 0 across FLIGHT051/052 (CH1 wiring) | hardware, physical inspection |
| Second FLIGHT052 reset (~434 ms after the late-flight pyro fire) — VBAT-rail-sag-under-ignition-load hypothesis, untested | test — bench-fire on the actual flight battery with high-rate voltage logging |
| `rf95.send()` has no audited internal timeout; shares the SD's SPI bus and is a plausible watchdog-reset candidate if a marginal radio module ever stalls | firmware, flagged not fixed — see `Telemetry.h` |
| Verify `Wire.setTimeOut()` compiles/behaves as expected against the installed ESP32 Arduino core version | test, before flashing v13 |
| Bench-test the RTC resume path itself: force a reset mid-`GROUND_TEST_MODE` run and confirm the FC comes back in the correct phase with `resumed=1` in the log | test, before flight |
| MPU6050 AD0 tied to GND | hardware |
| BMP180 CSB/VDDIO → VCC_3V3, SDO → GND | hardware, next PCB rev |
| `tilt_deg` is misnamed — it accumulates angular travel, never decreases | firmware |
| 4-hour rail standby (ECS 9.1.3) — light sleep, GPS backup mode | firmware |
| RRC3 backup "Drogue Delay" — recommend lowering from 3 s to 1 s (RRC3's minimum) against the 30 m/s drogue rating; not a firmware change, configured on the RRC3 itself | hardware/ops, see project's RRC3 doc |

---

---

# IGNIS v2 Flight Computer — firmware v12

**Date:** 2026-08-15
**Baseline:** `IGNIS_FC_heavy_11`
**Trigger:** FLIGHT016 / FLIGHT018 pulley tests + a correction from E. Guadarrama on battery state of charge

---

## What the pulley tests proved

Two 3-metre hand-pulley lifts against the avionics tower. Both ran the full
state machine `1 → 2 → 3 → 5 → 6 → 7` with `deploy_trigger = 1`.

**Three things worked, and they are worth recording:**

1. **CH2 fired a real e-match, with electrical proof.** `pyro2_cont` dropped
   from 1 to 0 exactly 24 ms after the fire command in both tests — the
   bridgewire opening. The channel switches real load and the CH2 continuity
   sense is functional. (CH1 remains stuck at 0.)
2. **No reset during firing.** `boot_count` held at 46 and 49 throughout, with
   456 and 587 rows logged *after* the fire. The v11 post-pyro forced flush
   works; there is no forensic hole any more.
3. **The stagger held exactly.** 1.524 s and 1.500 s measured against the
   1500 ms configured.

**And one thing failed badly.**

| | Peak AGL | BOOST detected | AGL at drogue fire |
|---|---|---|---|
| FLIGHT016 | 4.47 m @ t=95.04 | t=95.88 (0.84 s **after** peak) | +1.02 m |
| FLIGHT018 | 2.52 m @ t=21.54 | t=23.05 (1.51 s **after** peak) | **−0.80 m** |

In both tests BOOST triggered *after* the high point — the accelerometer fired
on the braking jerk of the descent, not on the lift. FLIGHT018 then commanded
the drogue **0.80 m below the launch reference**.

Operationally: an armed rocket carried to the pad and bumped could fire the
drogue in someone's hands.

Measured pre-BOOST handling noise peaked at **1.931 g** (F016) and **2.169 g**
(F018) — above the v11 threshold of 1.8 g. That threshold was calibrated
against FLIGHT072 pad data with the vehicle sitting still on a rail
(max 1.543 g over 380 s), which is not the same scenario as handling. **The
v11 threshold recommendation was wrong for that reason.**

---

## Changes

### 1. Boost debounce: 40 → 250 ms — `Config.h`

Level cannot discriminate a bump from a burn. **Duration can.**

Longest continuous run above 1.8 g:

| Log | Sustained |
|---|---|
| FLIGHT072 (real KNSU motor) | **2111 ms** |
| FLIGHT016 (pulley jerk) | 80 ms |
| FLIGHT018 (pulley jerk) | 93 ms |

Two orders of magnitude apart. 250 ms rejects handling transients with ~2.7×
margin and accepts a real burn with ~8× margin.

### 2. Minimum-altitude interlock — `Config.h`, `FlightState.h`

`MIN_APOGEE_ALT_M = 30.0f`. No pyro decision of any kind — neither barometric
apogee nor the timeout failsafe — is permitted until peak AGL since liftoff
has exceeded this.

This is **not** a "fire at altitude X" gate. That class of logic is what would
have suppressed FLIGHT072 entirely. This is a minimum-altitude-*ever-reached*
interlock evaluated against `maxAglSinceBoost`. FLIGHT072 peaked at 74.08 m,
so 30 m still deploys it with 2.4× margin.

Trade accepted, stated plainly: a vehicle that fails below 30 m AGL gets no
deployment. At that altitude a parachute does not change the outcome.

### 3. `GROUND_TEST_MODE` — `Config.h`, `FlightState.h`, `.ino`

Lowers the interlock to 1.5 m and the debounce to 40 ms so the pyro chain can
still be exercised on a pulley. Prints an unmissable boot banner when on.

**Must be `false` for flight.** With it off, pulley tests will no longer fire —
that is the correct consequence. The pulley validates the electrical chain;
the vacuum chamber validates flight logic.

### 4. `SINGLE_EVENT_MODE` — `Config.h`, `FlightState.h`

When true, `PYRO_CH2` is never fired. REC 8.1.2 exempts vehicles below 1500 m
AGL from dual-event, so single deployment at apogee is compliant at the 1000 m
target.

This matters beyond simplification: firing a channel into an open loop is
itself a reset risk on this hardware (unprotected gate opto — see the `Pyro.h`
header and the FLIGHT072 mid-air reset). **An unused channel must be disabled
in firmware, not merely left unwired.**

Set to `false` only when both channels are wired and both read `cont:OK`.

Cost of single-event at 1000 m: descent under the main from apogee at 7.5 m/s
is ~133 s, which is roughly 1.3 km of drift at the 10 m/s launch wind limit
(FLT 4.3.3). That is a team decision, not a firmware one.

### 5. Battery NO-GO — `Config.h`, `Sensors.h`, `.ino`, `StatusIndicator.h`, `Dashboard.h`

There was no battery threshold anywhere in the codebase before v12.
`battery_v` was logged and transmitted, and nothing evaluated it.

`VBAT_NOGO_V = 7.80`, `VBAT_WARN_V = 8.00`.

`readBattery()` extracted from `readSensors()` in `Sensors.h` so `setup()` can
evaluate it before the first sensor loop.

Critically, the battery is folded into the **persistent** indicators, not just
the boot tone: `preflightNoGo()` now drives the LED2 blink and the dashboard
status text. A one-shot boot tone is easy to miss if the board powers up while
being handled or already inside the airframe.

**Advisory only.** Like continuity, this never inhibits firing — `VBAT_MON` is
a resistor divider into an ADC, and a bad reading must not be able to cancel a
good flight. The veto belongs to the crew and the ground station.

### 6. `reset_reason` decode corrected — `Dashboard.h`, `groundstation/*`

The v11 tables mapped **6** to BROWNOUT. In `esp_reset_reason_t`, 6 is
`ESP_RST_TASK_WDT` and BROWNOUT is **9**. The `.ino` was always correct
because it used the named constants; the display paths were not.

Full table now decoded in all three places (dashboard, GS header, Python
parser), and the parser distinguishes crash reasons (4, 5, 6, 7, 15) from
brownout (9) — they point at different root causes.

### 7. Ground station alarm thresholds — `groundstation/telemetry_parser_v12.py`

Raised to match `Config.h`. The old 7.0 V warning would have shown FLIGHT072
(7.73 V) as green.

Verified against FLIGHT072's exact conditions — CH1 open, VBAT 7.73 V, reset
reason 4 — the parser now raises all three alarms.

---

## An open question this version does NOT close

The FLIGHT072 mid-air reset is still unexplained.

The v11 changelog implied the pulley tests ruled out a power-related cause.
**They did not.** Those tests ran at 8.10–8.12 V; FLIGHT072 flew at 7.73 V
(~45% SoC). That is an uncontrolled variable, not a negative result.

Three candidate mechanisms remain:

| Hypothesis | Expected `reset_reason` |
|---|---|
| A. GPIO overload from the unprotected gate opto (~80 mA into a 40 mA pin) | 4 (PANIC) or 15 (CPU_LOCKUP) |
| B. Genuine brownout | **9** |
| C. Firmware crash in the fire path, independent of battery | 4, 5, 6 or 7 |

Note that a pure VBAT-sag mechanism does not survive arithmetic: reaching the
AMS1117-5.0 dropout from 7.73 V needs ~1.5 V of droop, which at a 2S pack's
60–100 mΩ would require 15–25 A. FLIGHT072's CH1 was **open** — no pyro
current flowed at all. The only load step was the gate opto, ~80 mA, worth
about 8 mV. Something else is going on.

**The deciding test:** discharge a pack to 7.73 V — matching, not
approximating — and repeat the pulley sequence five times with
`GROUND_TEST_MODE = true` and a real e-match. From v11 onward the FC records
`reset_reason` itself, so the next reset will name its own cause.

---

## Still open after v12

| Item | Owner |
|---|---|
| 330 Ω series resistor on both pyro gate legs | hardware |
| Move the e-match to CH1 (currently on CH2) | hardware |
| MPU6050 AD0 tied to GND | hardware |
| BMP180 CSB/VDDIO → VCC_3V3, SDO → GND | hardware, next PCB rev |
| `tilt_deg` is misnamed — it accumulates angular travel, never decreases. Rename to `angular_travel_deg` or implement true quaternion tilt | firmware |
| Repeat the pulley test at 7.73 V to close the reset question | test |
| 30-minute idle soak to check whether `boot_count` self-increments | test |
| 4-hour rail standby (ECS 9.1.3) | firmware |
| Pad antenna geometry — RSSI −123.6 dBm is below the SF9 sensitivity floor | ground ops |

---

---

# IGNIS v2 Flight Computer — firmware v11

**Date:** 2026-08-15
**Baseline:** `IGNIS_FC_heavy_10`
**Trigger:** FLIGHT072 / FLIGHT073 post-mortem (Ignitia Rocket Lab, Mission ID 22)
**Author of changes:** avionics review, pending bench validation by E. Guadarrama

> Every change below is traced to a specific number in the FLIGHT072 SD log,
> the FLIGHT073 SD log, or GSLOG003. Nothing here is a guess. Where a value
> still needs to be tuned by the team, it is marked **TUNE**.

---

## What actually happened on FLIGHT072

| Event | FC clock | AGL |
|---|---|---|
| Armed | 2.4 s | 0 m |
| Liftoff detected (STATE_BOOST) | 384.63 s | 4.42 m |
| Burnout (STATE_COAST) | 386.39 s | 48.1 m |
| Apogee (true) | 387.93 s | **74.08 m** |
| Drogue fire commanded (STATE_DROGUE_DESCENT) | 388.12 s | 72.2 m |
| **FC reboot** | ~388.1–389.3 s | ~65 m |
| Ground impact (computed) | ~391.8 s | 0 m |

**The flight software worked.** Apogee was detected 188 ms after the true
peak — better than the 4-sample / 50 ms specification implies. The failure
was not in the detection logic.

**Three findings drove this revision:**

1. **CH1 (drogue) had no continuity — ever.** `pyro1_cont = 0` across all
   10,226 rows of FLIGHT072 and all 12,970 rows of FLIGHT073. `pyro2_cont = 1`
   across both. Per the polarity documented in `Pyro.h` (opto U7/PC817 pulls
   the sense line HIGH through VCC_3V3 when the loop is intact; R19 pulls it
   LOW when open), `cont = 0` means **open**. The FC commanded a fire into an
   open channel. The boot banner printed `CH1(drogue): OPEN` before the
   flight and nobody was looking at a serial console.

2. **The FC rebooted in mid-air, not on impact.** Reconstructed from GSLOG003:
   the last in-flight packet was `seq 377 / fc_t 387648`; the next packet was
   `seq 0 / fc_uptime 2084`. Free fall from 74 m takes 3.88 s, placing impact
   at ~391.8 s. The reset happened 2.5–3.7 s earlier, roughly 65 m above
   ground, within ~1.2 s of the pyro gate going HIGH. **Because CH1 was open,
   no pyro current flowed** — which rules out VBAT sag and points at the
   unprotected gate opto documented in `Pyro.h`'s own header.

3. **The liftoff threshold had 0.22 g of margin.** `BOOST_ACCEL_THRESHOLD_G`
   was 3.0 g; peak `accel_total_g` was 3.222 g. A motor 7 % weaker would have
   left the FSM in `STATE_ARMED` for the entire flight.

---

## Changes

### 1. Liftoff threshold: 3.0 g → 1.8 g — `Config.h`

Justified against 380 s of measured pad data from FLIGHT072:

| Metric (STATE_ARMED, t < 383.5 s) | Value |
|---|---|
| mean `accel_total_g` | 1.0001 g |
| p99.9 | 1.148 g |
| absolute max | 1.543 g |
| samples above 1.8 g | **0** |

Margin goes from 0.22 g to 1.42 g. Debounce raised 30 → 40 ms (2 loop ticks).

### 2. Barometric liftoff backup — `Config.h`, `FlightState.h`

New OR-path into `STATE_BOOST`: sustained baro climb rate ≥ 15.0 m/s for
≥ 150 ms. Survives a dead IMU.

FLIGHT073 proved this case is real, not hypothetical: after impact the
MPU6050 stopped validating (`imu_valid = 0` across all 12,970 rows) while the
BMP180 on the same I2C bus kept working. Threshold sits above the measured
pad climb-rate noise peak of 9.88 m/s.

The accel path now also requires `imu_reading_valid` — previously a stale
`accel_total_g` from a failed read could in principle satisfy the threshold.

### 3. Failsafe timeouts — `Config.h`, `FlightState.h`

| Constant | Value | Purpose |
|---|---|---|
| `BURNOUT_TIMEOUT_MS` | 4000 | force COAST if BOOST persists |
| `APOGEE_TIMEOUT_MS` | 20000 | **TUNE** — force APOGEE if the baro chain never closes |

`APOGEE_TIMEOUT_MS` is measured from burnout, not from liftoff. 20 s suits the
nominal 1000 m profile (~14 s burnout-to-apogee, plus margin).

> **TUNE THIS BEFORE EVERY FLIGHT.** Set it from the OpenRocket
> burnout-to-apogee time plus margin. Too short means a deployment at high
> speed and a shredded parachute. If the Brazilian propellant gives a
> different apogee, this number changes with it.

`deploy_trigger` records which path fired: `1` = barometric apogee,
`2` = timeout failsafe. If a flight comes back with `2`, the barometer chain
needs investigation regardless of whether recovery succeeded.

### 4. Drogue → main stagger — `Config.h`, `FlightState.h`

`MAIN_MIN_DELAY_AFTER_DROGUE_MS = 1500`.

Previously, any flight whose apogee was below `MAIN_DEPLOY_ALT_AGL_M` fired
both channels within one 20 ms loop tick (documented in the old `Pyro.h`
header as expected behaviour). FLIGHT072's 74 m apogee was exactly that case.
Simultaneous firing doubles peak current draw at the worst possible instant.

### 5. Post-pyro forced SD flush — `Config.h`, `FlightData.h`, `DataLogger.h`

Zero rows survived between the drogue fire (388.116 s) and the reset ~1.2 s
later. At a 20–40 ms loop that is roughly 40 lost rows — exactly the window
with diagnostic value. The state-change `forceFlush` committed the fire row
itself; the next scheduled flush (`LOG_FLUSH_INTERVAL_MS = 1000`) never
arrived before power was lost.

Every row within `PYRO_FORCE_FLUSH_MS` (4000 ms) of any fire event is now
committed immediately. `lastPyroEventMs` is declared in `FlightData.h`, not
`Pyro.h`, because `DataLogger.h` is included *before* `Pyro.h` in the sketch.

### 6. Boot counter and reset reason — `.ino`, `FlightData.h`, `DataLogger.h`, `Telemetry.h`

`boot_count` persists in NVS (`Preferences`, namespace `ignis`, key `boots`)
and is written into every SD row and telemetry packet, alongside
`esp_reset_reason()`.

A mid-flight reboot is now visible directly in the flight log instead of
requiring cross-reference against a ground station packet sequence counter.
`reset_reason = 6` is `ESP_RST_BROWNOUT`.

### 7. Audible NO-GO on open continuity — `StatusIndicator.h`, `.ino`, `Dashboard.h`

New `NOGO_MELODY` (low, slow, descending) and `playNoGoTone()`. Plays three
times at boot with all LEDs red if either channel reads open, after
`initStatusIndicator()` has brought up the buzzer PWM channel and the WS2812
strip.

The FLIGHT072 information existed on the serial console. Audio does not
require a laptop.

### 8. Gate drive-strength mitigation — `Pyro.h`

`gpio_set_drive_capability(..., GPIO_DRIVE_CAP_1)` (~10 mA) on both pyro gate
pins, guarded by `PYRO_GATE_REDUCED_DRIVE`.

**This is not the fix.** The fix is a 330 Ω series resistor on each gate leg,
per the hardware flag already documented in `Pyro.h`'s header (the PC817 LED
is driven with no series resistor; an ESP32-S3 GPIO into that load can pull
~80 mA through a ~25 Ω driver).

Under-driving an opto can also make it **fail to switch**, which is the more
dangerous failure direction. If you enable this you must verify on the bench
that a real e-match fires 5 times out of 5 on the flight battery. If that test
does not pass cleanly, set `PYRO_GATE_REDUCED_DRIVE` to `false` and do the
resistor bodge instead.

### 9. Tilt estimate — logged only — `Config.h`, `FlightState.h`

Integrated off-boost-axis gyro rate, zeroed until `STATE_BOOST`.

**It never gates a pyro decision, and it must not.** LASC's 15° attitude limit
is a fail-safe requirement for missions with an Attitude Control System; this
vehicle has no ACS, so it does not apply. An integrated-gyro estimate drifts
badly — FLIGHT072 accumulated 538° of roll in 3.5 s — and a tumbling vehicle
at apogee is precisely when the parachute is most needed. A tilt-based
deployment inhibit would convert a recoverable abnormal trajectory into a
ballistic entry.

The field exists for post-flight analysis and for trajectory evidence at the
Launch Operation Debriefing (FLT 4.2.11).

---

## Telemetry packet — BREAKING CHANGE

Four fields appended at the end of `TelemetryPacket`.

| Version | Payload | ToA @ SF9 / BW125 / CR4-5 |
|---|---|---|
| v10 | 90 B | 545.8 ms |
| **v11** | **98 B** | **566.3 ms** |

`TELEMETRY_INTERVAL_MS_FLT` is 600 ms, so v11 still fits — but the margin is
34 ms. If you need it back, drop `mpu_temp_c` from the packet (it stays in the
SD log regardless).

> Note: the v10 header comment estimated ~98 B for the v10 packet. The
> measured `struct.calcsize` value is 90 B. The ToA figures above are computed
> from Semtech AN1200.22 with explicit header, 8-symbol preamble, CRC on.

**You must update `IGNIS_GroundStation.ino` and the Python parser in the same
commit.** See `groundstation/`. The struct is `__attribute__((packed))`; any
misalignment decodes silently into garbage rather than failing loudly.

---

## Not changed, deliberately

- **Apogee detection** (`APOGEE_FALLING_SAMPLES = 4`, `APOGEE_MIN_SAMPLE_INTERVAL_MS = 50`).
  It delivered 188 ms latency on FLIGHT072. Leave it alone.
- **Single vs dual event.** REC 8.1.2 exempts vehicles below 1500 m AGL from
  dual-event, so a single deployment is permitted at the 1000 m target. The
  code remains dual-event with the Tender Descender. This is a team decision,
  not a firmware one.
- **`MAIN_DEPLOY_ALT_AGL_M = 450`.** Compliant with REC 8.1.4 (≤ 500 m AGL).
- **RSSI/SNR on the FC side.** Still left at 0; the radio only transmits.

---

## Open items this firmware does NOT fix

| Item | Owner |
|---|---|
| 330 Ω series resistor on both pyro gate legs | hardware |
| Determine which channel the e-match is physically wired to | hardware |
| MPU6050 AD0 tied to GND (floating; suspected FLIGHT073 IMU loss) | hardware |
| BMP180 CSB/VDDIO → VCC_3V3, SDO → GND | hardware, next PCB rev |
| 40.2 % telemetry packet loss; pad RSSI −123.6 dBm, SNR −12.9 dB | ground ops |
| 4-hour rail standby (ECS 9.1.3) — light sleep, GPS backup mode | firmware, not in v11 |

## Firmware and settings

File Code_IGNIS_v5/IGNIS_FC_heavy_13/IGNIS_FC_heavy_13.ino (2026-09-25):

/*
  ================================================================
  IGNIS v2 Flight Computer — Main Sketch
  Ignitia Rocket Lab — LASC 2026, Rocket Challenge (Mission ID 22)
  ================================================================
  BEFORE THIS COMPILES you must fill in every TODO pin in Config.h:
  I2C_SDA/SCL, WS2812_DATA, PYRO1/2_FIRE, PYRO1/2_CONT, VBAT_MON,
  RFM95_CS/RST/DIO0. Confirm each against your schematic — especially
  the pyro pins. Do not fly on guessed pins.

  Libraries required (Library Manager):
    TinyGPSPlus, RadioHead, Adafruit NeoPixel
  (MPU6050 and BMP180 are raw-register drivers in Sensors.h — no
   Adafruit_MPU6050 / Adafruit_BMP085 library needed for those two.
   SHT40 removed — not used on this build.)

  Flow: (power applied via RBF pull-pin = physically armed) -> boot ->
        STATE_ARMED -> BOOST -> COAST -> APOGEE (drogue fires) ->
        DROGUE_DESCENT -> (450m AGL, main fires) -> MAIN_DESCENT -> LANDED
        ...UNLESS this boot is a RESUME (v13, see below): in that case
        setup() skips straight into whatever phase the RTC record says
        the vehicle was already in, instead of starting this flow over
        from STATE_ARMED.

  v13 (2026-09-22) — post-FLIGHT051/052 revision. See docs/CHANGELOG.md:
    - RTC-persisted resume across an in-flight reset: setup() previously
      had no concept of "we already launched," so ANY in-flight reset
      (including the confirmed ESP_RST_INT_WDT reset between FLIGHT051
      and FLIGHT052) restarted the whole state machine from STATE_ARMED,
      requiring boost/apogee to be re-detected from scratch. Now a
      resumed boot skips MPU calibration (also wrong to redo on a moving
      body), skips re-arming, and reopens the SAME SD file instead of
      starting a new one.
    - pyro1_fired/pyro2_fired are now part of that persisted record —
      previously RAM-only, meaning a reset after a successful fire could
      let a later boot try to re-fire an already-spent (burned-open)
      channel.
    - Wire.setTimeOut() + runtime I2C bus recovery (Sensors.h), and a
      bounded post-pyro SD flush interval instead of flushing every row
      (DataLogger.h) — both aimed at the confirmed watchdog-reset root
      cause, not just its symptoms.
    - RTC "last operation" breadcrumb: any future reset now shows not
      just THAT it happened (reset_reason) but WHAT the FC was doing
      right before (I2C read / SD write / SD mount / radio send / pyro
      fire / MPU calibration) — see FlightData.h's RtcFlightState.
    - Removed the hardcoded FLIGHT072 callouts from the LIVE dashboard
      (Dashboard.h) — kept once, here, in the boot-time NO-GO banner,
      instead of repeating on every dashboard refresh in flight.

  v11 (2026-08-15) — post-FLIGHT072 revision. See CHANGELOG_v11.md. Summary:
    - Liftoff threshold 3.0 g -> 1.8 g (FLIGHT072 peaked at 3.222 g)
    - Barometric liftoff backup path (survives a dead IMU)
    - Burnout + apogee failsafe timeouts
    - Minimum drogue->main stagger
    - Post-pyro forced SD flush window
    - NVS boot counter + reset reason (mid-flight reboot detection)
    - Audible NO-GO on open pyro continuity
    - Integrated-gyro tilt estimate (LOGGED ONLY, never gates pyro)

  v12 (2026-08-15) - post-FLIGHT016/018 pulley tests. See CHANGELOG_v12.md:
    - Boost debounce 40 -> 250 ms (pulley jerks were triggering BOOST)
    - MIN_APOGEE_ALT_M interlock: no pyro decision below 30 m peak AGL
    - GROUND_TEST_MODE for bench/pulley work
    - SINGLE_EVENT_MODE: CH2 never fired (unused channel disabled, not just
      unwired - firing into an open loop is itself a reset risk)
    - Battery NO-GO folded into the persistent indicators, not just boot
    - reset_reason decode corrected: ESP_RST_BROWNOUT is 9, not 6

  ARMING IS PHYSICAL, NOT SOFTWARE: this board arms via the RBF pull-pin
  cutting/restoring battery power (ECS 7.2.2/9.1.6). There is no GPIO arm
  button — CONFIRMED with Emilio. By the time this firmware is running,
  the board is already live, so setup() transitions straight to
  STATE_ARMED once init is complete. Handle a powered board as LIVE PYRO
  at all times, including on the bench.
  ================================================================
*/

#include <Preferences.h>
#include "esp_system.h"
#include "Config.h"
#include "FlightData.h"
#include "DataLogger.h"     // must run its SPI.begin() before Telemetry.h uses the radio
#include "Sensors.h"
#include "Pyro.h"
#include "FlightState.h"
#include "Telemetry.h"
#include "StatusIndicator.h"
#include "Dashboard.h"      // must be included last — reads static state from the modules above

static FlightData fd;
static unsigned long lastSensorLoopMs = 0;
static unsigned long lastTelemetryMs = 0;

// Arming is physical (RBF pull-pin), not a GPIO — see header comment.
// No armButtonPressed() needed; setup() transitions to STATE_ARMED directly.

void setup() {
  Serial.begin(115200);
  delay(200);
  Serial.println("=== IGNIS v2 Flight Computer (v13) — boot ===");
  Serial.println("!!! Board is physically armed via RBF pull-pin. If power is applied, pyro is LIVE. !!!");

  // ---- BROWNOUT / RESET FORENSICS (v11) ----
  // FLIGHT072 rebooted in mid-air roughly 65 m above ground, ~2.5 s before
  // impact, within ~1.2 s of the drogue gate going HIGH. The ONLY reason we
  // know that is that the ground station happened to see the packet sequence
  // counter reset to 0. The FC itself had no record. Now it does: boot_count
  // is persisted in NVS and written into every SD row and telemetry packet,
  // so a mid-flight reboot is visible directly in the flight log.
  {
    Preferences prefs;
    prefs.begin("ignis", false);
    fd.boot_count = prefs.getUShort("boots", 0) + 1;
    prefs.putUShort("boots", fd.boot_count);
    prefs.end();
  }
  fd.reset_reason = (uint8_t)esp_reset_reason();

  // ---- RESUME DETECTION (v13) ----
  // Confirmed via FLIGHT051/052 telemetry: FLIGHT051 ended mid-STATE_COAST
  // (before any pyro fire) with the next boot's reset_reason = 5
  // (ESP_RST_INT_WDT) — a real in-flight reset, not a bench/pad reset. A
  // resume is only attempted when BOTH of these hold: this was NOT a clean
  // power-on (rules out a normal fresh flight, or a deliberate bench power
  // cycle), AND the RTC record's magic number is valid with a phase that
  // shows the vehicle was already at/past STATE_BOOST (rules out treating
  // an unrelated reset while just sitting on the pad as a resume). If the
  // RTC domain itself lost power (a brownout severe enough to fully cycle
  // it), rtcState.magic will simply not match and this falls back to the
  // old cold-start behavior automatically — no special-casing needed.
  bool rtcValid  = (rtcState.magic == RTC_FLIGHT_MAGIC);
  bool wasFlying = rtcValid && (rtcState.phase >= (uint8_t)STATE_BOOST);
  bool isResume  = RTC_RESUME_ENABLED &&
                    (fd.reset_reason != ESP_RST_POWERON) &&
                    wasFlying;
  fd.resumed_this_boot = isResume;

  Serial.printf("[BOOT] boot_count=%u  reset_reason=%u %s  last_op=%s\n",
                (unsigned)fd.boot_count, (unsigned)fd.reset_reason,
                (fd.reset_reason == ESP_RST_BROWNOUT) ? "*** BROWNOUT ***" :
                (fd.reset_reason == ESP_RST_PANIC)    ? "*** PANIC ***"    :
                (fd.reset_reason == ESP_RST_WDT ||
                 fd.reset_reason == ESP_RST_TASK_WDT ||
                 fd.reset_reason == ESP_RST_INT_WDT)  ? "*** WATCHDOG ***"  : "",
                rtcValid ? rtcLastOpName(rtcState.lastOp) : "n/a (no RTC record)");

  if (isResume) {
    Serial.println("################################################################");
    Serial.println("###  RESUME: this looks like an in-flight reset, not a fresh  ###");
    Serial.printf ("###  boot. Resuming from phase=%-14s instead of re-arming. ###\n",
                   flightStateName((FlightState_t)rtcState.phase));
    Serial.println("################################################################");
  }

  bool sensorsOk = initSensors(isResume);
  Serial.printf("[BOOT] Sensors: %s\n", sensorsOk ? "OK" : "DEGRADED");

  initPyro();
  if (isResume) {
    // Restore the one-shot fire latches BEFORE anything else can call
    // fireDrogue()/fireMain() — see Pyro.h's fireChannel() header comment
    // on why a RAM-only latch is a re-fire risk across a reset.
    fd.pyro1_fired = rtcState.pyro1_fired;
    fd.pyro2_fired = rtcState.pyro2_fired;
  }
  checkPyroContinuity(fd);
  Serial.printf("[BOOT] Pyro continuity — CH1(drogue): %s  CH2(main): %s\n",
                fd.pyro1_continuity ? "OK" : "OPEN",
                fd.pyro2_continuity ? "OK" : "OPEN");
  bool pyroNoGo = (!fd.pyro1_continuity || !fd.pyro2_continuity);
  readBattery(fd);   // populate battery_v before the NO-GO evaluation below
  bool battNoGo = (fd.battery_v < VBAT_NOGO_V);
  Serial.printf("[BOOT] VBAT: %.2f V  %s\n", fd.battery_v,
                battNoGo ? "*** BELOW NO-GO THRESHOLD ***" :
                (fd.battery_v < VBAT_WARN_V) ? "(low - consider a fresh pack)" : "OK");

  bool sdOk = initDataLogger(isResume);
  Serial.printf("[BOOT] SD logging: %s\n", sdOk ? "OK" : "DISABLED (continuing)");

  bool loraInitOk = initTelemetry();
  Serial.printf("[BOOT] LoRa telemetry: %s\n", loraInitOk ? "OK" : "DISABLED (continuing)");

  initStatusIndicator();

  // ---- AUDIBLE PRE-FLIGHT NO-GO (v11) ----
  // Must come AFTER initStatusIndicator(), which is where the buzzer PWM
  // channel and the WS2812 strip are actually brought up. See the NOGO_MELODY
  // comment in StatusIndicator.h for why this exists.
#if GROUND_TEST_MODE
  Serial.println("################################################################");
  Serial.println("###  GROUND_TEST_MODE IS ON - THIS IS NOT FLIGHT CONFIG       ###");
  Serial.printf ("###  min apogee alt lowered to %.1f m, debounce to %lu ms      ###\n",
                 (double)GROUND_TEST_MIN_ALT_M, (unsigned long)GROUND_TEST_DEBOUNCE_MS);
  Serial.println("###  Set GROUND_TEST_MODE to false in Config.h before flight. ###");
  Serial.println("################################################################");
#endif

  if (pyroNoGo || battNoGo) {
    Serial.println("################################################################");
    if (pyroNoGo) {
      Serial.println("###  NO-GO: PYRO CONTINUITY OPEN                             ###");
      Serial.printf ("###  CH1(drogue): %-6s   CH2(main): %-6s               ###\n",
                     fd.pyro1_continuity ? "OK" : "OPEN",
                     fd.pyro2_continuity ? "OK" : "OPEN");
      Serial.println("###  FLIGHT072 flew with CH1 OPEN and never ignited.         ###");
    }
    if (battNoGo) {
      Serial.printf ("###  NO-GO: VBAT %.2f V (threshold %.2f V)                 ###\n",
                     fd.battery_v, (double)VBAT_NOGO_V);
      Serial.println("###  FLIGHT072 flew at 7.73 V (~45% SoC).                    ###");
    }
    Serial.println("###  ADVISORY ONLY - the FC will still arm and still fire.    ###");
    Serial.println("###  Resolve this BEFORE installing the board in the airframe.###");
    Serial.println("################################################################");
    playNoGoTone(3);
  }

  if (isResume) {
    // v13: skip the ARMED re-arm entirely — resumeFlightState() (FlightState.h)
    // sets fd.state directly from the persisted phase, restores
    // maxAglSinceBoost/ground-pressure calibration, and re-arms the
    // relevant phase timers against the new clock. See its header comment
    // and RtcFlightState in FlightData.h for what is and isn't preserved.
    resumeFlightState(fd);
    updateStatusIndicator(fd);
    Serial.printf("=== Boot complete — RESUMED into %s (LIVE PYRO). ===\n",
                  flightStateName(fd.state));
  } else {
    // No software arm step exists on this hardware — the RBF pull-pin is
    // the sole arm/safe gate, and it already happened before this code ran.
    // Go straight to ARMED so the LED/buzzer correctly reflect LIVE PYRO
    // from the moment boot completes.
    fd.state = STATE_ARMED;
    updateStatusIndicator(fd); // red: ARMED, LIVE PYRO
    playMelodyBlocking(ARMED_MELODY, ARMED_MELODY_LEN); // boot-safe blocking (pre-loop) — see StatusIndicator.h
    Serial.println("=== Boot complete — ARMED (LIVE PYRO). ===");
  }
}

void loop() {
  unsigned long now = millis();

  // ---- Main sensor / state loop (~50 Hz) ----
  if (now - lastSensorLoopMs >= SENSOR_LOOP_INTERVAL_MS) {
    lastSensorLoopMs = now;

    FlightState_t stateBefore = fd.state;

    readSensors(fd);
    checkPyroContinuity(fd);
    // RSSI/SNR intentionally NOT read here — CONFIRMED via bench test to
    // always read the register reset value (-157dBm / 0.0dB, unvarying)
    // because this radio only ever transmits; RegRssiValue/RegPktSnrValue
    // only update in RX mode. Real link-quality numbers live on the
    // ground station (IGNIS_GroundStation.ino), which is the actual
    // receiver. fd.rssi_dbm/snr_db are left at 0 — see FlightData.h.

    updateFlightState(fd);
    maintainPyroPulses(); // non-blocking pulse-off — see Pyro.h header for why this replaced delay()
    rtcSyncFlightState(fd); // v13 — keeps the resume record current every tick, see FlightState.h

    bool stateChanged = (fd.state != stateBefore);
    logFlightData(fd, stateChanged); // force flush on any state transition
    updateStatusIndicator(fd);
    maintainHeartbeatBeep(fd); // slow standby beep while PAD_IDLE/ARMED — silent once flying
  }

  // ---- SD retry-on-timer (no-op if already logging or session ended) ----
  maintainSDConnection(fd.state);

  // ---- Telemetry loop (rate depends on phase) ----
  unsigned long telInterval = (fd.state <= STATE_ARMED)
                                 ? TELEMETRY_INTERVAL_MS_PAD
                                 : TELEMETRY_INTERVAL_MS_FLT;
  if (now - lastTelemetryMs >= telInterval) {
    lastTelemetryMs = now;
    sendTelemetry(fd);
  }

  // ---- Terminal state: keep logging/telemetry alive, close file once stable ----
  static bool logClosed = false;
  if (fd.state == STATE_LANDED && !logClosed) {
    closeLog();
    logClosed = true;
    Serial.println("[SD] Log closed — safe for recovery.");
  }

  // ---- Live status dashboard (self-throttled, see Dashboard.h) ----
  updateDashboard(fd, now);
}

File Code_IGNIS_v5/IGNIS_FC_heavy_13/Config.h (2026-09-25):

/*
  ================================================================
  IGNIS v2 Flight Computer — Config.h
  Ignitia Rocket Lab — LASC 2026 (Mission ID 22)
  ================================================================
  PSRAM RESERVED PINS — never assign these to anything, ever:
    IO35, IO36, IO37  (Octal PSRAM data/strapping)
    IO45 must float (strapping pin)

  Pins below marked CONFIRMED were read off your schematic images.
  Pins marked TODO are NOT in anything you've shared with me — they
  are wired to trigger a compile error until you fill them in from
  the schematic. This is deliberate, especially for the pyro pins.
  ================================================================
*/

#pragma once

// ---------------- CONFIRMED PINS (from schematic) ----------------
#define SD_MOSI_PIN       11   // net: SNS_SPI_MOSI
#define SD_MISO_PIN       13   // net: SNS_SPI_MISO
#define SD_SCK_PIN        12   // net: SNS_SPI_SCK
#define SD_CS_PIN         42   // net: SD_CS
#define SD_DETECT_PIN     41   // net: SD_DETECT

// CONFIRMED from full MCU pinout sheet (Microcontroller - ESP32-S3).
#define BUZZER_PIN        14   // net: BUZZER — also verified working standalone

// GPS UART pair — CONFIRMED pins from schematic, direction INFERRED from
// device-centric net naming convention (GPS_UART_TX = GPS module's own TX
// pin, GPS_UART_RX = GPS module's own RX pin — consistent with how
// RFM95W_CS/RFM95W_RESET etc. are named after the device side, not the
// ESP32 side). This means ESP32 RX = IO17, ESP32 TX = IO18 — the OPPOSITE
// of the previous placeholder. GPS is non-critical to flight logic
// (initSensors() doesn't require it), so verify on the bench: if no fix /
// no NMEA chatter, try swapping.
#define GPS_RX_PIN        17   // ESP32 RX <- GPS TX (net GPS_UART_TX)
#define GPS_TX_PIN        18   // ESP32 TX -> GPS RX (net GPS_UART_RX)

// ---------------- TODO PINS — fill in from schematic ----------------
#define I2C_SDA_PIN       21   // CONFIRMED: net SNS_I2C_SDA
#define I2C_SCL_PIN       38   // CONFIRMED: net SNS_I2C_SCL (NOT IO37 — verify against your board silk if unsure)

#define WS2812_DATA_PIN    6   // CONFIRMED: net WS2812B_DATA — drives 3 chained WS2812B LEDs (see StatusIndicator.h)

#define PYRO1_FIRE_PIN     4   // CONFIRMED: net PYRO_CH1_GATE
#define PYRO2_FIRE_PIN     5   // CONFIRMED: net PYRO_CH2_GATE
#define PYRO1_CONT_PIN     1   // CONFIRMED: net PYRO_CH1_CONT (digital, opto per schematic)
#define PYRO2_CONT_PIN     2   // CONFIRMED: net PYRO_CH2_CONT

// NOT APPLICABLE on this hardware — CONFIRMED with Emilio: arming is
// purely physical, via the RBF pull-pin that cuts/restores battery power
// (ECS 7.2.2/9.1.6). There is no GPIO arm signal to read. By the time this
// firmware is running at all, the board is already live — see IGNIS_FC.ino,
// which now boots directly into STATE_ARMED at the end of setup() instead
// of polling a button that doesn't exist.

#define VBAT_MON_PIN       3   // CONFIRMED: net VBAT_MON

#define RFM95_CS_PIN      10   // CONFIRMED: net RFM95W_CS
#define RFM95_RST_PIN      8   // CONFIRMED: net RFM95W_RESET
#define RFM95_DIO0_PIN     7   // CONFIRMED: net RFM95W_INT
// CONFIRMED from schematic: RFM95W shares the SD SPI bus (SNS_SPI_MISO/
// MOSI/SCK, same nets/pull-ups R24-27 feed both the SD slot and the LoRa
// module) with its own CS pin. See DataLogger.h — SPI.begin() (the global
// SPI object) must run unconditionally regardless of SD card presence.
#define RFM95_SHARES_SD_SPI_BUS  true

// NOT WIRED INTO FIRMWARE YET — present on schematic, unused by this code:
//   MPU6050_INT -> IO9   (interrupt-driven IMU reads instead of polling)
//   FIX_GPS     -> IO35  *** CONFLICT: IO35 is a reserved Octal PSRAM pin
//                          on your N16R8 module. Do NOT connect/use this
//                          until you've confirmed with the schematic
//                          author whether this net actually needs moving. ***
//   BOOT        -> IO0   (standard strapping pin, not a general GPIO here)

#if (I2C_SDA_PIN < 0) || (I2C_SCL_PIN < 0)
#error "Config.h: set I2C_SDA_PIN / I2C_SCL_PIN from your schematic before compiling."
#endif
#if (WS2812_DATA_PIN < 0)
#error "Config.h: set WS2812_DATA_PIN from your schematic before compiling."
#endif
#if (PYRO1_FIRE_PIN < 0) || (PYRO2_FIRE_PIN < 0) || (PYRO1_CONT_PIN < 0) || (PYRO2_CONT_PIN < 0)
#error "Config.h: pyro pins are NOT SET. Confirm every pyro pin against the schematic yourself before compiling — this is not something to guess."
#endif
#if (VBAT_MON_PIN < 0)
#error "Config.h: set VBAT_MON_PIN from your schematic before compiling."
#endif
#if (RFM95_CS_PIN < 0) || (RFM95_RST_PIN < 0) || (RFM95_DIO0_PIN < 0)
#error "Config.h: set RFM95_CS_PIN / RFM95_RST_PIN / RFM95_DIO0_PIN from your schematic before compiling."
#endif
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

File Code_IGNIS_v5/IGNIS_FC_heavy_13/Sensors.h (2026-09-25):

/*
  ================================================================
  IGNIS v2 Flight Computer — Sensors.h
  Raw-register BMP180 + MPU6050 drivers (no Adafruit_BMP085/MPU6050
  abstraction layer), GPS. SHT40 removed — not used on this build.

  Why raw register drivers for BMP180/MPU6050:
    - Per-reading validity (I2C failure or out-of-range result) is
      checked and reported, instead of silently trusting whatever the
      library handed back. This matters specifically because this
      board has a known floating-CSB failure mode that produces
      corrupted/halved BMP180 pressure values that still LOOK like
      plausible numbers.
    - Exact datasheet LSB/unit scale factors are used directly,
      instead of going through a library's own internal constants.
    - Chip-ID / WHO_AM_I checks catch a dead/miswired sensor at boot
      instead of silently returning zeros forever.

  Design choice — "hold last-known-good on a bad read": when a single
  BMP180 or MPU6050 read is rejected, the corresponding FlightData
  fields are NOT overwritten with zeros/garbage — they keep their last
  valid value, and *_reading_valid is set false for that sample. This
  means every downstream consumer (FSM thresholds, telemetry, CSV log,
  dashboard) automatically falls back to the last trustworthy value
  without needing its own validity-gating logic scattered everywhere.
  The one place that DOES explicitly gate on validity is the apogee
  detector in FlightState.h, because that's the one place a single
  corrupted-but-plausible sample could directly cause an early pyro
  fire — see the comment there.

  MANDATORY: the I2C bus MUST be preconditioned (SDA/SCL driven HIGH
  then released to INPUT) before Wire.begin() on this hardware, due
  to the floating BMP180 CSB pin on the current PCB rev. We also run
  a 9-clock stuck-bus recovery right after, covering a second/
  different I2C fault mode (a slave holding SDA low mid-transaction).
  Doing both, in sequence, doesn't assume which one you're hitting on
  any given boot.
  ================================================================
*/

#pragma once
#include <Wire.h>
#include <TinyGPSPlus.h>
#include <math.h>
#include "Config.h"
#include "FlightData.h"

static TinyGPSPlus       gps;
static HardwareSerial    gpsSerial(1); // UART1

static bool mpuOk = false;
static bool bmpOk = false;

// ================================================================
// I2C bus preconditioning + recovery
// ================================================================
static void i2cPrecondition(int sdaPin, int sclPin) {
  pinMode(sdaPin, OUTPUT);
  pinMode(sclPin, OUTPUT);
  digitalWrite(sdaPin, HIGH);
  digitalWrite(sclPin, HIGH);
  delay(10);
  pinMode(sdaPin, INPUT);
  pinMode(sclPin, INPUT);
  delay(10);
}

// Classic 9-clock stuck-bus recovery: if a slave is holding SDA low
// mid-transaction, toggling SCL up to 9 times gives it enough clock
// edges to finish whatever it thought it was doing and release the
// bus. Distinct fault mode from the floating-CSB issue above — this
// one's about a slave stuck mid-byte, not a bad idle-state voltage.
static void recoverI2CBus(int sdaPin, int sclPin) {
  pinMode(sdaPin, INPUT_PULLUP);
  pinMode(sclPin, INPUT_PULLUP);
  delay(10);

  pinMode(sclPin, OUTPUT);
  for (int i = 0; i < 9; i++) {
    if (digitalRead(sdaPin) == HIGH) break;
    digitalWrite(sclPin, LOW);
    delayMicroseconds(10);
    digitalWrite(sclPin, HIGH);
    delayMicroseconds(10);
  }
  pinMode(sclPin, INPUT_PULLUP);
  pinMode(sdaPin, INPUT_PULLUP);
  delay(10);
}

// ================================================================
// BMP180 — raw register driver
// ================================================================
#define BMP180_REG_CHIP_ID  0xD0
#define BMP180_REG_CONTROL  0xF4
#define BMP180_REG_RESULT   0xF6
#define BMP180_CMD_TEMP     0x2E
#define BMP180_CMD_PRESSURE 0x34

static int16_t  bmpAC1, bmpAC2, bmpAC3;
static uint16_t bmpAC4, bmpAC5, bmpAC6;
static int16_t  bmpB1, bmpB2;
static int16_t  bmpMB, bmpMC, bmpMD;

static bool bmpWrite8(uint8_t reg, uint8_t value) {
  Wire.beginTransmission(BMP180_ADDR);
  Wire.write(reg);
  Wire.write(value);
  return Wire.endTransmission() == 0;
}

static bool bmpReadBytes(uint8_t reg, uint8_t* buffer, uint8_t len) {
  Wire.beginTransmission(BMP180_ADDR);
  Wire.write(reg);
  if (Wire.endTransmission(false) != 0) return false;

  uint8_t received = Wire.requestFrom((uint8_t)BMP180_ADDR, len);
  if (received != len) return false;

  for (uint8_t i = 0; i < len; i++) buffer[i] = Wire.read();
  return true;
}

static uint8_t bmpRead8(uint8_t reg) {
  uint8_t value = 0;
  bmpReadBytes(reg, &value, 1);
  return value;
}

static uint16_t bmpReadU16BE(uint8_t reg) {
  uint8_t b[2];
  if (!bmpReadBytes(reg, b, 2)) return 0;
  return ((uint16_t)b[0] << 8) | b[1];
}

static int16_t bmpReadS16BE(uint8_t reg) {
  return (int16_t)bmpReadU16BE(reg);
}

static bool bmpReadCalibration() {
  bmpAC1 = bmpReadS16BE(0xAA);
  bmpAC2 = bmpReadS16BE(0xAC);
  bmpAC3 = bmpReadS16BE(0xAE);
  bmpAC4 = bmpReadU16BE(0xB0);
  bmpAC5 = bmpReadU16BE(0xB2);
  bmpAC6 = bmpReadU16BE(0xB4);
  bmpB1  = bmpReadS16BE(0xB6);
  bmpB2  = bmpReadS16BE(0xB8);
  bmpMB  = bmpReadS16BE(0xBA);
  bmpMC  = bmpReadS16BE(0xBC);
  bmpMD  = bmpReadS16BE(0xBE);

  if (bmpAC1 == 0 || bmpAC1 == -1) return false;
  if (bmpAC4 == 0 || bmpAC4 == 65535) return false;
  if (bmpAC5 == 0 || bmpAC5 == 65535) return false;
  if (bmpAC6 == 0 || bmpAC6 == 65535) return false;
  return true;
}

static bool bmp180Begin() {
  uint8_t chipID = bmpRead8(BMP180_REG_CHIP_ID);
  Serial.printf("[BMP180] Chip ID: 0x%02X\n", chipID);

  if (chipID != 0x55) {
    Serial.println("[BMP180] ERROR: not detected correctly (check CSB tied to VCC_3V3, VDDIO, SDO).");
    return false;
  }
  if (!bmpReadCalibration()) {
    Serial.println("[BMP180] ERROR: failed to read calibration data.");
    return false;
  }
  Serial.println("[BMP180] Calibration loaded.");
  return true;
}

static bool bmpReadRawTemperature(int32_t& UT) {
  if (!bmpWrite8(BMP180_REG_CONTROL, BMP180_CMD_TEMP)) return false;
  delay(5);
  UT = bmpReadU16BE(BMP180_REG_RESULT);
  return true;
}

static bool bmpReadRawPressure(int32_t& UP, uint8_t oss) {
  uint8_t b[3];
  uint8_t command = BMP180_CMD_PRESSURE + (oss << 6);
  if (!bmpWrite8(BMP180_REG_CONTROL, command)) return false;
  // Datasheet max conversion time by OSS: 4.5/7.5/13.5/25.5 ms for 0/1/2/3.
  // +a few ms margin rather than shaving it exactly to the datasheet min.
  static const uint8_t ossDelayMs[4] = {5, 8, 14, 27};
  delay(ossDelayMs[oss & 0x03]);
  if (!bmpReadBytes(BMP180_REG_RESULT, b, 3)) return false;
  UP = (((int32_t)b[0] << 16) | ((int32_t)b[1] << 8) | b[2]) >> (8 - oss);
  return true;
}
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

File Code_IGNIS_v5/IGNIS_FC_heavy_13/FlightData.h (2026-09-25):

/*
  ================================================================
  IGNIS v2 Flight Computer — FlightData.h
  Single canonical data struct shared by Sensors, FlightState, Pyro,
  Telemetry, and DataLogger — avoids field drift between modules.
  ================================================================
*/

#pragma once
#include <Arduino.h>
#include "esp_attr.h"   // RTC_DATA_ATTR — see RtcFlightState below (v13)

enum FlightState_t : uint8_t {
  STATE_PAD_IDLE = 0,
  STATE_ARMED,
  STATE_BOOST,
  STATE_COAST,
  STATE_APOGEE,
  STATE_DROGUE_DESCENT,
  STATE_MAIN_DESCENT,
  STATE_LANDED
};

inline const char* flightStateName(FlightState_t s) {
  switch (s) {
    case STATE_PAD_IDLE:        return "PAD_IDLE";
    case STATE_ARMED:           return "ARMED";
    case STATE_BOOST:           return "BOOST";
    case STATE_COAST:           return "COAST";
    case STATE_APOGEE:          return "APOGEE";
    case STATE_DROGUE_DESCENT:  return "DROGUE_DESCENT";
    case STATE_MAIN_DESCENT:    return "MAIN_DESCENT";
    case STATE_LANDED:          return "LANDED";
    default:                    return "UNKNOWN";
  }
}

struct FlightData {
  unsigned long timestamp_ms = 0;
  FlightState_t state = STATE_PAD_IDLE;

  // BMP180
  float pressure_pa   = 0;
  float baro_alt_m    = 0;   // absolute (sea-level reference)
  float agl_m         = 0;   // computed directly from pressure ratio vs ground pressure — see FlightState.h
  float baro_temp_c   = 0;
  bool  baro_reading_valid = false;  // false = last read rejected (I2C fail or out-of-range) — fields above hold last-known-good, not garbage

  // SHT40 removed — not used on this build.

  // MPU6050
  float accel_x_g = 0, accel_y_g = 0, accel_z_g = 0;
  float accel_total_g = 0;              // raw magnitude — used by the FSM (fast reaction, no added lag)
  float accel_total_g_filtered = 0;     // lightly smoothed (EMA) — display/logging only, NOT used by the FSM
  float gyro_x_dps = 0, gyro_y_dps = 0, gyro_z_dps = 0;   // bias-corrected against boot-time calibration
  float mpu_temp_c = 0;                 // MPU6050's own temp sensor — free from the same burst read, useful cross-check
  bool  imu_reading_valid = false;      // false = last read rejected (I2C fail) — fields above hold last-known-good

  // GPS
  double gps_lat = 0, gps_lon = 0;
  float  gps_alt_m = 0;
  uint8_t gps_sats = 0;
  bool    gps_fix = false;

  // Power / RF
  float battery_v = 0;
  int   rssi_dbm = 0;
  float snr_db = 0;

  // Pyro
  bool pyro1_continuity = false, pyro2_continuity = false;
  bool pyro1_fired = false, pyro2_fired = false;

  // --- Forensics / diagnostics (added v11, after FLIGHT072) ---
  float    tilt_deg       = 0;   // integrated-gyro tilt estimate. DRIFTS. Diagnostic only, never gates pyro.
  uint16_t boot_count     = 0;   // NVS-persisted. An increment mid-flight == the FC rebooted mid-flight.
  uint8_t  reset_reason   = 0;   // esp_reset_reason(); 9 == ESP_RST_BROWNOUT on ESP32-S3, not 6 (see v12 note)
  uint8_t  deploy_trigger = 0;   // 0=none  1=barometric apogee  2=TIMEOUT FAILSAFE

  // --- Resume forensics (added v13, after FLIGHT051/052) ---
  bool resumed_this_boot  = false;  // true if setup() resumed mid-flight state instead of cold-starting into STATE_ARMED — see RtcFlightState below
};

// Timestamp of the most recent pyro fire event. Declared HERE rather than in
// Pyro.h on purpose: DataLogger.h needs it for the post-fire forced-flush
// window, and DataLogger.h is included BEFORE Pyro.h in the main sketch.
// Written by fireChannel(), read by logFlightData().
static unsigned long lastPyroEventMs = 0;

// ================================================================
// RTC-persisted flight session state (v13)
// ----------------------------------------------------------------
// Added after FLIGHT051/052: setup() had no concept of "we already
// launched," so any in-flight reset (including the confirmed
// ESP_RST_INT_WDT reset between those two files) restarted the whole
// state machine from STATE_ARMED, requiring boost/apogee to be
// re-detected from scratch and losing the descent as one continuous
// record. This struct is what setup() checks to resume instead.
//
// RTC_DATA_ATTR places it in the ESP32's "RTC slow memory," which is
// NOT cleared by a software/panic/watchdog reset (only by a genuine
// power-on / full power cycle of the RTC domain) — that's the entire
// mechanism this depends on. It is NOT guaranteed to survive every
// brownout severity: if VBAT sags hard enough to fully power-cycle the
// RTC domain, this is lost too, and the FC falls back to the old
// cold-start behavior automatically (see the magic-number check in
// IGNIS_FC_heavy_13.ino's setup()). Bench-test which case this
// project's brownout protection actually produces before flying on the
// assumption that resume always works.
//
// Deliberately NOT attempting to reconstruct absolute mission-elapsed
// time across the reset: millis() restarts at 0 on every reboot, so
// per-phase timers (coastEnteredMs, landedStableSinceMs, etc., all in
// FlightState.h) are simply re-armed fresh on resume rather than
// carried across the reset boundary. This is a conservative
// simplification, not a correctness bug — it can only make a failsafe
// timer fire a little later than it would have with zero downtime,
// never early, and it doesn't affect the primary sample-based
// apogee/landed detectors at all, which don't depend on elapsed time.
// ================================================================

#define RTC_FLIGHT_MAGIC  0x49474E31UL   // 'IGN1' — bump this if RtcFlightState's layout changes, so a firmware update never misreads a stale record left by an older build

enum RtcLastOp_t : uint8_t {
  OP_IDLE = 0,
  OP_I2C_READ,
  OP_SD_WRITE,
  OP_SD_MOUNT,
  OP_RADIO_SEND,
  OP_PYRO_FIRE,
  OP_MPU_CAL,
};
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

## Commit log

2026-09-25 Initial project structure
    [Main.SchDoc, PCB_IGNIS-v5.PcbDoc, PCB_Project_IGNIS-v5.PrjPcb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]
2026-09-25 Add schematic sheets and component libraries
    [1729160.SchLib, 1N4148W.SchLib, 82_SMA-50-0-41_133_NE.STEP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]
2026-09-26 Main and Power sheets done, LoRa/GPS nearly done, parts list rev5
    [AMASS_XT30PW-M.PcbLib, BAT_WIRELESS_BWSMA-KE-Z001.PcbLib, ESP32-S3-WROOM-1-N16R8.SchLib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]
2026-09-29 Sensors and RF/GPS sheets: LSM6DSV32X and DPS368 wiring, SAM-M10Q review fixes
    [Indicators.SchDoc, LGA-14L_2p5X3p0X0p86_STM.step, LSM6DSV32XTR.PcbLib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]
2026-11-10 v5 FC: project skeleton, v5 pin map, flight config, secrets template, partitions
    New firmware folder Code_IGNIS_v5/IGNIS_v5_FC (reference IGNIS_FC_heavy_13 untouched).
    - pins_v5.h: pin map from Main.SchDoc net labels + PCB ECO pad numbers;
    unconfirmed pins tagged TODO(v5-unconfirmed)
    - config_v5.h: flight constants ported from reference Config.h with line refs,
    compile-time feature flags, REBOOT_FIRE_POLICY, GROUND_TEST_MODE flight guard
    - partitions.csv: two OTA slots for rollback
    - secrets_example.h template; secrets.h gitignored
2026-11-10 v5 FC core: flight state machine and pyro latch logic + host tests
    Pure C++ (no Arduino) so the FSM is testable on the host.
    - flight_fsm: port of reference FlightState.h (boost debounce + baro backup,
    burnout, falling-window apogee, APOGEE_TIMEOUT failsafe, MIN_APOGEE_ALT_M
    interlock, drogue->main stagger, SINGLE_EVENT_MODE, landed detection).
    v5: SAFE/ARMED mirror the continuity signal (fail closed), RECOVERY is a
    terminal state that never requests a fire. FSM emits requests only.
    - pyro_logic: one-shot latch set at gate-on, non-blocking pulse, one-way
    recovery lockout (reference Pyro.h:116-160).
    - host tests: 13 FSM scenarios incl. timer rollover; run_host_tests.ps1 (zig).
    Co-A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
2026-11-10 v5 FC core: boot policy (post-fire RECOVERY) and OTA gate + host tests
    - boot_policy: non-power-on reset with flight_in_progress/post_fire (NVS or
    RTC mirror) -> RECOVERY; flags cleared only on ESP_RST_POWERON; unreadable
    NVS on a non-POR reset fails closed to RECOVERY.
    - ota_gate: OTA denied on continuity (either channel), invalid continuity,
    state != SAFE, flight latched, post-fire, recovery boot, or OTA not built.
2026-11-10 v5 FC core: 98-byte telemetry packet, RadioHead framing, NMEA parser, CSV row + tests
    - telemetry_packet: byte-identical to reference Telemetry.h:55-104
    (static_assert size 98 + key offsets). RECOVERY sent as state=8, no new
    fields. RadioHead 4-byte header emulated for the existing ground station.
    Verified: a v5-encoded packet decodes correctly with the unmodified
    reference telemetry_parser_v12.py.
    - nmea: GGA/RMC with checksum enforcement (replaces TinyGPSPlus).
    - csv_row: reference column order kept, v5 diagnostic columns appended.
    - groundstation/telemetry_parser_v5.py: same format, state 0=SAFE, 8=RECOVERY.
2026-11-10 v5 FC hal: sensor, GPS, pyro, NVS, SPI bus, SD and LoRa task drivers
    - pyro_hw: gates LOW first at boot, continuity read (fail-closed valid flag),
    mirrors PyroLogic onto GPIO; reduced gate drive kept (ref Pyro.h:83-104).
    No disable/kill/test-fire API.
    - nvs_state: flight/post-fire flags written only on transitions, per-channel
    fired mask, RTC_NOINIT mirror, erase only on power-on reset.
    - imu_lsm6dsv32x / baro_dps368: raw-register drivers, chip-ID probe on both
    strap addresses, hold-last-known-good. Registers marked TODO(v5-verify).
    - i2c_bus: Wire timeout + 9-clock recovery (ref Sensors.h:68-89, 587-599).
    - gps_battery: in-tree NMEA, unconfirmed GPS control pins left as inputs.
    - sp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
2026-11-10 v5 FC net: read-only WiFi SoftAP dashboard and gated OTA
    - wifi_dashboard: AP off at boot, started by holding BOOT 2 s on the pad,
    WPA2 from gitignored secrets.h (8-63 chars static_assert), 1 client, HT20,
    esp_wifi_set_max_tx_power, core 0 prio 1. GET-only: page, /api/state
    (cached at WIFI_SNAPSHOT_HZ), SD list/download only in SAFE with one SPI
    lock per 1 KB. Latched off at BOOST / never on RECOVERY; loop() backstop.
    - ota_update: digest auth (separate OTA password), X-Image-SHA256 checked
    before boot switch, esp_ota_end image verification, gate checked at start,
    every chunk, while idle and before set_boot_partition; stale snapshot =
    invalid continuity (fail closed).
    Co-Autho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
2026-11-10 v5 FC app: flight task, OTA self-test/rollback, main sketch boot sequence
    - flight_task: 50 Hz on core 1, TWDT-subscribed and fed after a full
    iteration; gate asserted before NVS post-fire write; BOOST latches WiFi
    off and persists flight_in_progress; RECOVERY locks pyro out before the
    first tick; tilt diagnostic only.
    - selftest: verifyRollbackLater()=true; after 3 s checks IMU, baro, SD,
    continuity inputs, TWDT subscription and loop progress; marks a pending
    OTA image valid or rolls back (never on RECOVERY / after flight latch).
    - sketch: gates LOW first, reset reason + boot policy, app SHA-256 logged
    at boot and on SD (BOOTLOG.TXT), recovery banner.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
2026-11-10 v5 FC SINGLE-DEPLOY core: CH2 backup charge, retry on intact e-match, resume after reboot
    Requested by the Avionics Lead for this single-deployment variant:
    - pyro_sequencer (replaces one-shot pyro_logic): CH1 primary at apogee, CH2
    backup charge always fired as soon as CH1's pulse ends; a channel that
    still reads continuity 250 ms after its pulse is re-fired 500 ms later, up
    to 3 attempts/channel; never two gates on; no new attempt after 10 s.
    Retries need a valid reading and pre-fire continuity on that channel.
    - pulse 1000 -> 500 ms, CH1->CH2 1500 -> 500 ms (late deployments broke the
    shock cord). 450 m main event removed (reference SINGLE_EVENT_MODE replaced).
    - flight_fsm: sin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
2026-11-10 v5 FC SINGLE-DEPLOY integration: NVS flight state, sequencer GPIO, boot modes, dashboard
    - nvs_state: persists phase (BOOST/COAST/DESCENT/LANDED), ground pressure and
    attempts per channel; transition-only writes; RTC mirror with checksum.
    - pyro_hw: pyroDrive() mirrors the sequencer onto the gates every tick.
    - flight_task: GPIO before persist; resume/lockout from the boot decision.
    - sketch: boot mode banner, variant name SINGLE-DEPLOY, WiFi only on NORMAL
    boots, gyro calibration only on NORMAL boots.
    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
2026-11-10 v5 FC drivers: verified against repo datasheets; fix LSM6DSV32X CTRL8 and RFM95W version check
    Datasheet check (PDFs in PCB_Project_IGNIS-v5/Components):
    - DPS368 (Infineon v1.1): register map, field encodings, soft reset, ID,
    coefficient packing, scale factors and compensation formulas all match.
    - LSM6DSV32X (DS13511 Rev 2): CTRL8 bit 2 must be written as 1 (Table 67);
    driver wrote 0x03 -> now 0x07 with 3-bit read-back. Everything else matches.
    - RFM95W (HopeRF): RegVersion listed as 0x11; driver accepted only 0x12 ->
    now accepts 0x11 or 0x12. RegSyncWord 0x39 not in the HopeRF table
    (Semtech SX1276 register, used by the reference). Rest matches.
    - CHANGES.md: datasheet results tab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
